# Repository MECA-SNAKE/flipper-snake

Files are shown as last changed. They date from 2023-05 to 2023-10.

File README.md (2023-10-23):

https://meca-snake.github.io/flipper-snake/

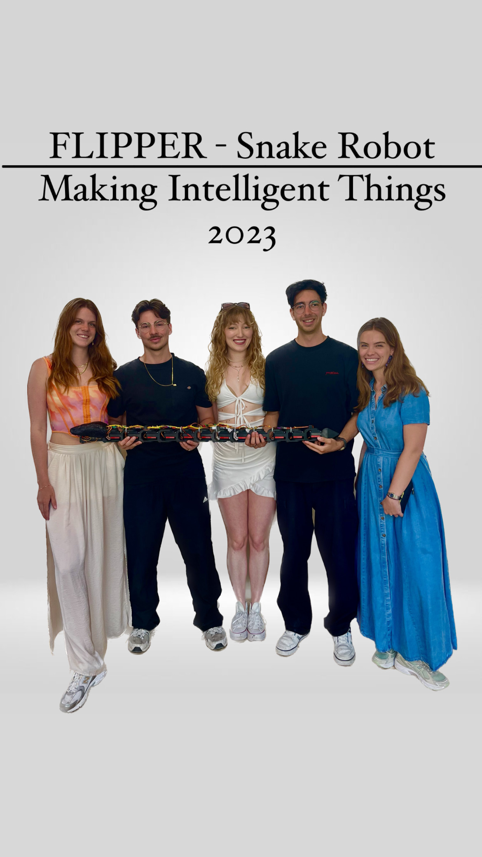
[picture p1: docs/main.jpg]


Meet Flipper, an impressive snake robot measuring 1m20 and crafted from 13 intricately designed 3D-printed pieces. With its remarkable capabilities, Flipper elegantly navigates and explores its surroundings. This versatile robot boasts 3 distinct modes of motion: Inchworm, Concertina, and Undulation. The Inchworm mode enables precise inch-by-inch movement, the Concertina mode mimics the graceful accordion-like motion. In the Undulation mode, Flipper effortlessly slithers with a mesmerizing sinusoidal movement. Flipper's innovative design and diverse locomotion options make it a remarkable robotic creation. 

## News
* May 2023: Present project outcome in a public forum
* June 2023: Invitation from the EPFL Computer Science and Communication Systems Section to present Flipper to the Section's teachers at the Lausanne Palace
* Octobre 2023: Invitation to the VIScon 2023 symposium at ETH in Zürich







## How to reproduce the snake

### Mount the snake
* Take the stl files of the snake. Print the main piece 8 times (the one without the holder for a battery), 3 times the one that can hold a battery, the tail one time, the head one time and the snake head on time. Pay attention to fully clean the holes for the wheels to avoid contact with the pieces
* Print also the 28 wheels and the 14 sticks to place them below the pieces
* Follow the first animation of the piece design section to mount the pieces together with the bearings and servos. Don’t forget to place the pieces that can hold a battery. You can place them where you want however keep in mind that they can help to pass cables through them. After that you should have a full length snake. 
* Mount the boards on the head piece as you will see in the animations, and the battery in its holder. A crucial stage now is to make the cable management. Follow the images and the details below in the readme to see how to connect all the cables, as well as connecting the cables to the PCA board, NodeMCU, the DC-to-DC converter and the battery. Exercise caution during this step, ensuring that you correctly connect the cables as per the provided diagram. Regarding the cable lengths required for a complete assembly, the yellow cable spans 5 meters, while the ground and the plus cables measure 3 meters each. For the head of the snake, you can place it as you want.

### Arduino code
* Download these following softwares on your computer : 
* the Arduino IDE app
* Set the Arduino IDE with NodeMCU ESP8266 (there are tutorials if needed on YouTube) 
* Add the board manager link in Arduino IDE Files < Preferences < Additional Board Manager URLs field : https://arduino.esp8266.com/stable/package_esp8266com_index.json 
* Install the esp8266 toolchain in the Tools -> Board -> Boards Manager
* Select Tools->Board->"ESP8266 Boards (some version)"->"NodeMCU V0.9 (ESP-12 Module)".
* And you may need to install : https://www.silabs.com/developers/usb-to-uart-bridge-vcp-drivers?tab=downloads

* Clone the Arduino code from the arduino-commands repository 
* Connect your computer to the ESP8266 board via a micro usb cable
* Change the ssid and password of your hotspot
* Upload the code to the board and connect the battery to the snake
* Verify in Serial Monitor that it prints Wifi Connected indicating that the board successfully connected to your wifi

### The React Native App
* Clone the react-native-esp-app repository locally on your machine. 
* Install NodeJS for your operating system
* Install expo-cli with this terminal command : `npm install -g expo-cli` / If there is a problem with windows restriction, copy paste this command into the Powershell `Set-ExecutionPolicy -Score CurrentUser -ExecutionPolicy RemoteSigned`
* Install expo client on your phone
* Navigate to the : react-native-esp-app folder on your computer. In App.tsx change line 53’s IP address with the IP address that will be printed in the Serial Monitor of the Arduino IDE app. 
* Write `expo start` in the terminal
* Scan the QR code with your phone, which will open the app

### How to launch the snake
* Enable your hotspot
* Start the app on your phone
* Connect the battery to the snake
* Have fun!

## Motivation 
Serpentine robots are a groundbreaking innovation in robotics, captivating researchers and engineers with their unique physical characteristics and versatile capabilities. These flexible and slithering machines excel at navigating complex and confined spaces, offering immense potential in various fields, including search and rescue operations, industrial inspections, exploration, medical applications, surveillance and security, and hazardous environments.

In search and rescue scenarios, robotic snakes play a crucial role. Unlike traditional robots, they excel at maneuvering through narrow and cluttered environments, such as collapsed buildings or debris. With their flexible bodies, they can easily navigate tight spaces, climb obstacles, and explore inaccessible areas. Equipped with cameras and sensors, these robots transmit real-time data, aiding rescuers in locating survivors and assessing surrounding conditions.

Our objective was to undertake a project that would have practical relevance in the real world. The field of robotics is continuously evolving, and we saw the development of a robotic snake as a chance to deepen our understanding of robotics and gain practical experience in designing and building complex systems. As a group of five computer scientists with backgrounds in communication systems and computer science, we possess a solid understanding of algorithms, programming languages, and system design, which are essential components in the development of a robotic system.

While we may not have had direct experience in building robotic systems, we embraced the opportunity to expand our expertise. We were committed to researching the specific technologies and methodologies required to develop a robotic snake, including mechanical engineering principles and electrical systems.

## Preparation for the project
After doing extensive research, we encountered 2 existing snake projects that served as profound inspiration for Flipper: 

* https://www.instructables.com/Bioinspired-Robotic-Snake/
* https://www.instructables.com/Snake-Robot-1/

Furthermore, our journey led us to a valuable encounter with a PhD student from the Bio-Robotic Lab at EPFL. During our conversation, she generously shared her insights and recommendations for a successful project within a shorter timeframe. One key suggestion was to focus on a signle degree of freedom for motion, ensuring efficiency and feasability. Additionally, she encouraged us to explore the mechanics behind sinusoidal functions, shedding light on the intriguing undulated motion exhibited by snakes. These valuable ideas and guidance have profoundly influenced our approach to Flipper's developpement. 

## Conception

### Material

* 1 LiPo Battery 2S 7.4V
* 1 ESP8266 microcontroller
* 1 PCA9685 servo motor controller
* 1 LM2596 DC-to-DC converter
* 12 DS6225MG Servo motors
* 48 M3 0.5 inserts
* 48 M3 10mm screws 
* 1 Adapter cable ModelCraft 58604
* A lot of cables and electric sheath
* 28 small lego wheels
* 2 Lasers 650mn 5V
* 12 bearings 12x8mm

### Piece design

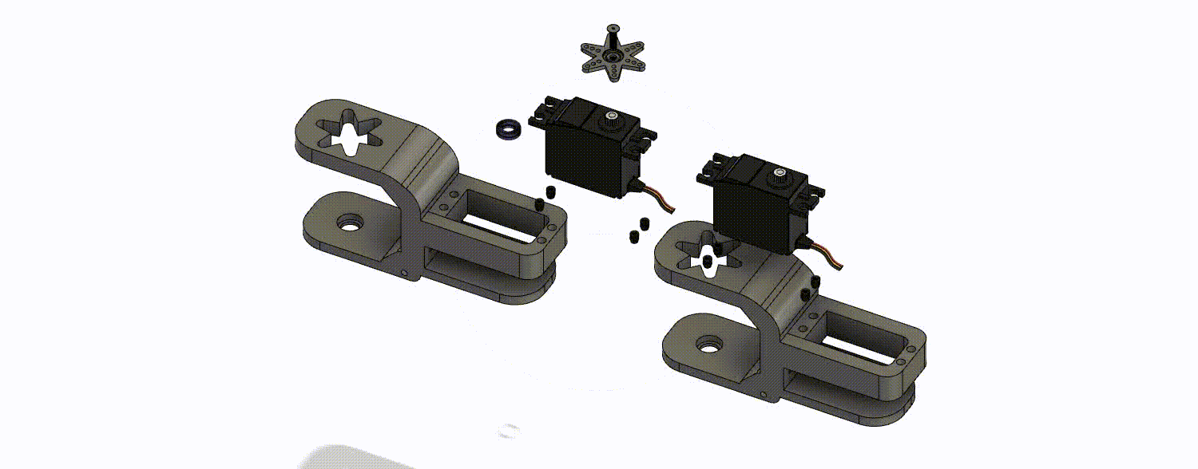
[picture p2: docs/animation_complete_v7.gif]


#### 1.Important features

Initially, our design concept for Flipper was relatively straightforward. However, as we delved deeper into the design and development process of the pieces, we faced a number of challenges. Our primary objective was to create a joint capable of achieving a broad range of motion, ideally spanning at least 180 degrees. Additionally, we strived to ensure that the servo was securely held in place, with minimal looseness or play. Overcoming these obstacles became essential in achieving the desired functionality and stability of Flipper's design.

To accomplish our goal, we developed an interlocking piece system featuring a single axis of rotation. This design enabled us to achieve a wide range of motion, spanning from approximately -30 to 230 degrees, with the middle position set at 90 degrees. By utilizing this system, we ensured that Flipper could move smoothly and effectively within this expansive range.
For the servo motor, we opted for a simple yet effective holder design. This holder featured four holes strategically positioned to allow us to securely fasten the servos in place. To further enhance stability and ensure a tight fit, we utilized inserts with the appropriate thread pitch.

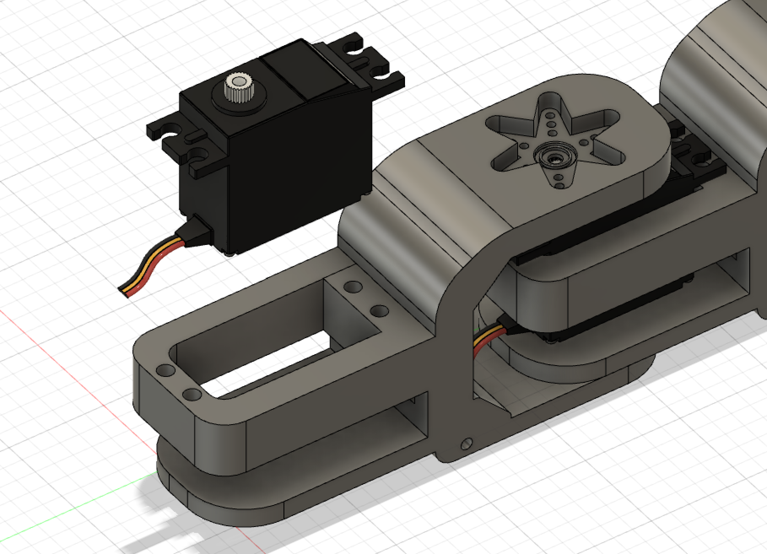
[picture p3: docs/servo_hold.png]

#### 2. Movement propagation

The subsequent obstacle we faced involved transmitting the motion from one piece to another along the servo's axis of rotation. To address this challenge, we leveraged the star-shaped mounting head of a servo as a reference point. By incorporating a corresponding hollow shape in our own piece design, we were able to seamlessly connect and interlock two segments (refer to the attached picture).

Our decision to utilize a star-shaped head stemmed from its advantageous feature of offering multiple points of contact with the subsequent piece. This choice greatly facilitated the transmission of movement, making it more manageable to drive the desired motion. 

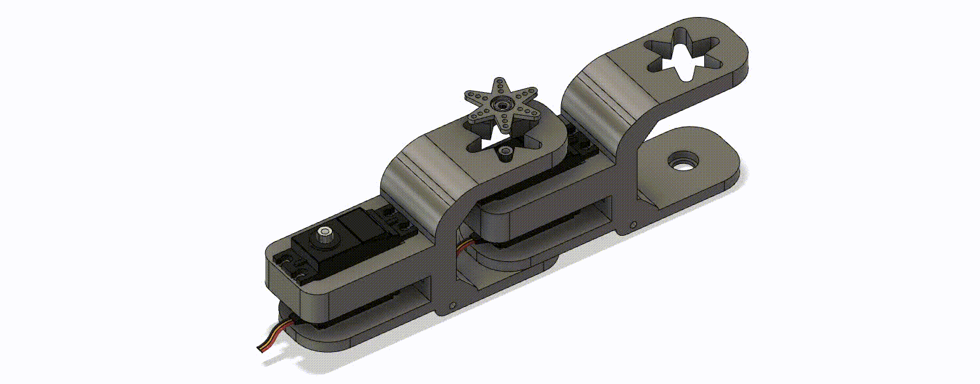
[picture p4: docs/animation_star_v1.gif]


To ensure a secure fit and prevent any dislocation, we implemented two additional features. Firstly, we created an extrusion beneath the surface of one piece, and corresponding to it, a hole in the second piece. This design allowed for a solid interlocking system between the two pieces.
Secondly, to minimize friction between the pieces, we incorporated a bearing. The extrusion was designed to fit snugly into the bearing, enabling smooth movement and reducing friction.
These modifications proved effective in achieving a well-fitting and stable assembly.

Although this approach proved highly successful, implementing the design was not without its challenges. The intricate shape posed complexities that necessitated multiple attempts and iterations. Through perseverance and a process of trial and error, we ultimately achieved a well-fitting shape that perfectly served our intended purpose.
 
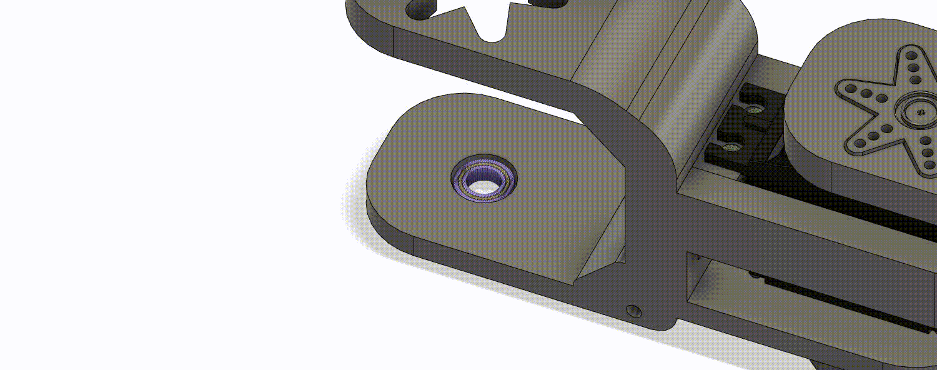
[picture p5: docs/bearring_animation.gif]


#### 3. Allowing movement

A fundamental and indispensable component that ensures the accurate movement of the snake is the incorporation of wheels. The lateral friction generated by these wheels imparts a unidirectional force, enabling the snake to move effectively. This mechanism aims to mimic the natural function of snake scales, which enhance friction in specific directions. Our primary objective was to minimize the visibility of the wheels, preventing any misperception that they are directly driving the snake's motion, contrary to its undulated movement. The meticulous effort invested in concealing the wheels yields a sleek and sophisticated design, emphasizing the clean aesthetics of the overall structure.

#### 4. Designing the Head

The design of the head was significantly influenced by our considerations for cable management and electronic components. Our goal was to accommodate a microcontroller, servo board, converter, and all the necessary circuit cables within the head. While the assembly of these components inside the head may appear somewhat intricate, we believe it to be a sound approach. This design choice offers the advantage of providing protection for all the internal elements, despite the potential complexity of the arrangement.

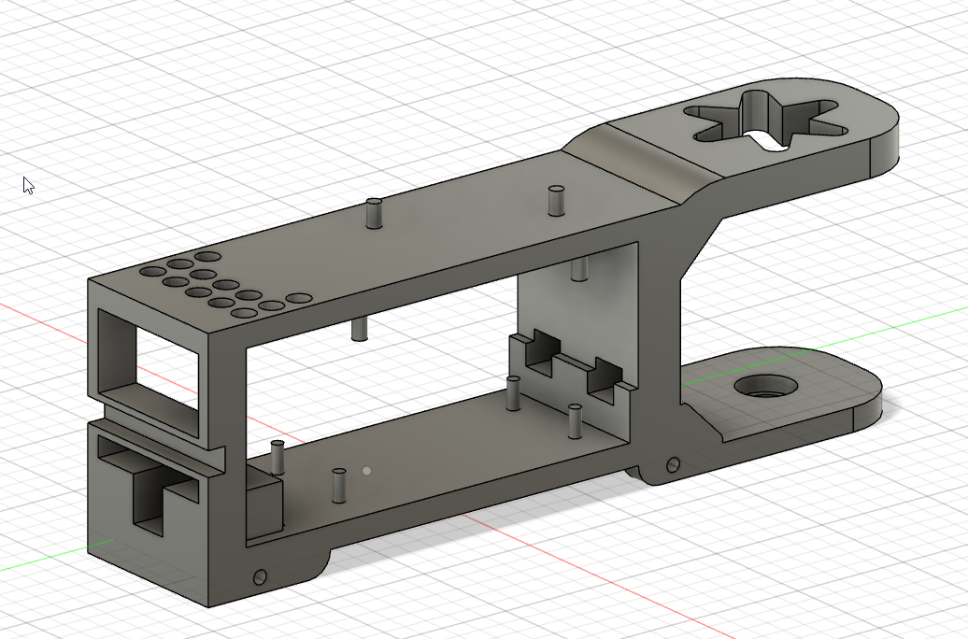
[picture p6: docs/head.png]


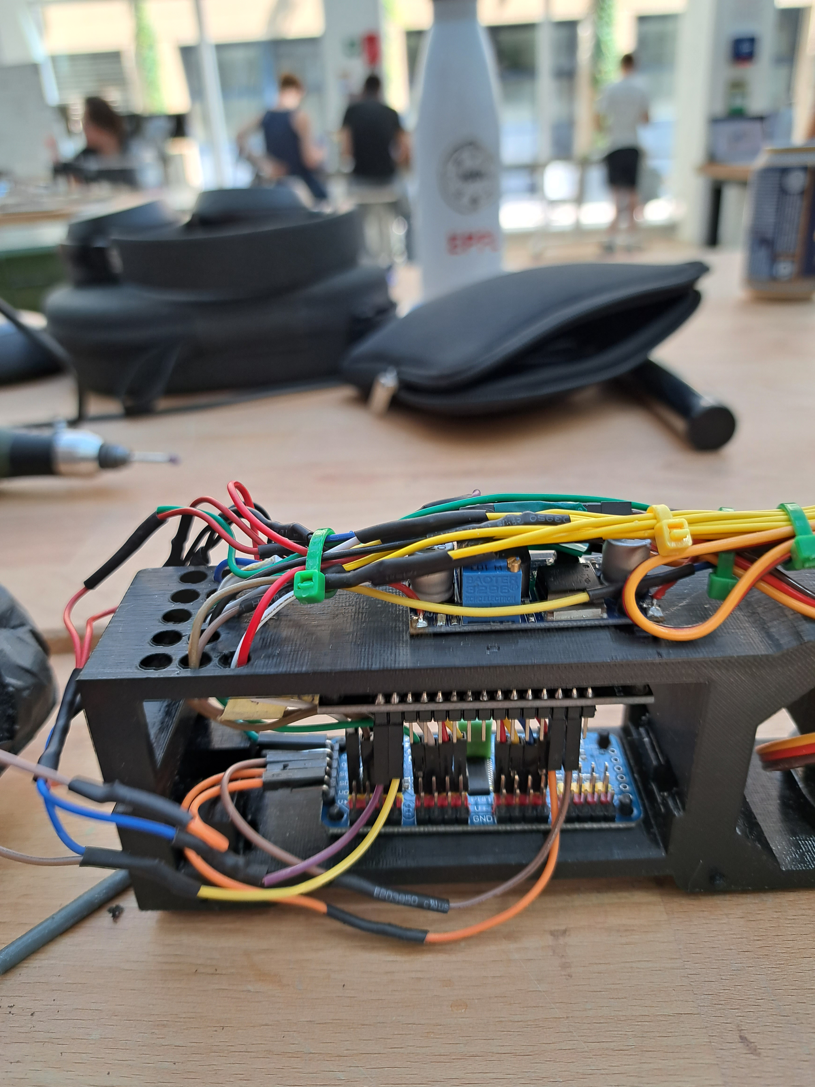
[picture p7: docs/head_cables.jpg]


#### 5. Thinking ahead

The design aspect of the project is of utmost importance, as even the smallest oversight could lead to the failure of the entire endeavor. We made a conscientious effort to anticipate and address all potential challenges that could arise. One such challenge was cable management. To ensure a polished end result, we incorporated holes in each piece to allow the cables to seamlessly traverse from the tail to the head. However, we encountered a setback as these holes turned out to be too small to accommodate the servo's cable end.

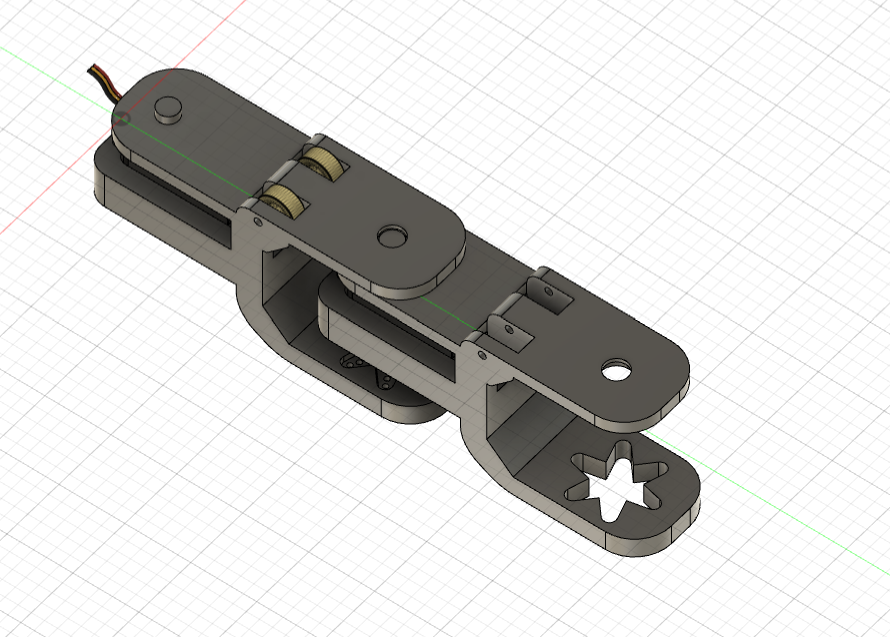
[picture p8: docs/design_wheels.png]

    
### Electronics

The primary role of our electronic components is to effectively control the servo motors. To accomplish this, we utilized a PCA9685 board specifically designed for transmitting PWM (Pulse-Width Modulation) signals to the servo motors. This board was then connected to our microcontroller, which housed the necessary code for servo movement. However, we encountered several challenges when it came to powering the entire circuit, which will be elaborated upon in the subsequent sections.

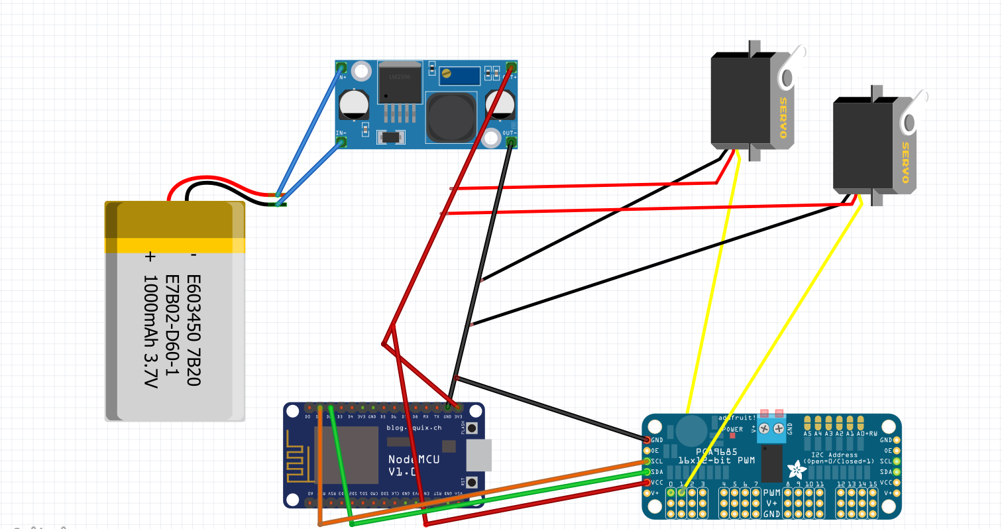
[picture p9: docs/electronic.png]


#### 1. Placing the Battery

Initially, our plan involved utilizing three 7.4V Lipo batteries, which necessitated careful consideration regarding their placement and accessibility. To securely accommodate these batteries, we devised three additional pieces with integrated holders. This design adaptation ensured that the batteries were not only firmly held within the snake but also easily replaceable when required.
However, following an extensive discussion with members of the DLL building and Professor Koch, we made the decision to reduce the battery count to just one. The consideration was primarily due to the challenges associated with parallel connection to achieve a higher current output, which could potentially risk damaging the batteries. Given that these batteries are specifically designed to deliver a significant amount of current within a short duration, opting for a single battery proved to be a prudent choice

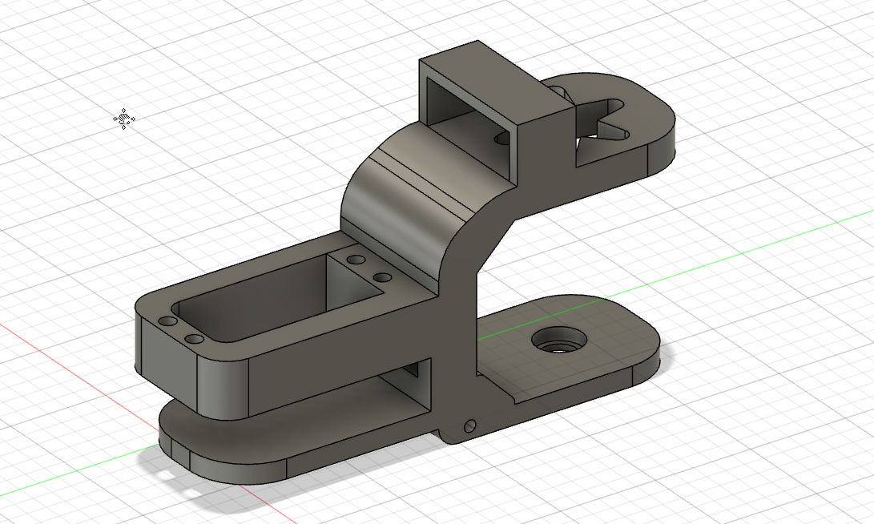
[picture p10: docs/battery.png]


#### 2. Powering the servos directly from the battery

Upon examining the electronic schema, an intriguing observation arises: the servo motors' positive and negative cables are not directly connected to the PCA9685. Instead, we have implemented a configuration where all the servo grounds are connected to the battery ground, and all the servo positive terminals are linked to the battery's positive terminal.
This unique arrangement serves a specific purpose within the circuit design, providing a common ground for the servos and maintaining a shared power source through the battery's positive terminal. In fact this idea was from our professor because we were worried that there would be too much current from the servos. Using only the signal pins means we don't have to power the servos via the PCA9685. 

#### 3. Voltage and Current

Our circuit design faces various constraints due to specific voltage and current requirements of different components:

* The servo motors operate within a voltage range of 4.8-6V.
* The ESP8366 module operates at 3.3V.
* The ESP8266 module requires a voltage supply of 5V.
* The battery supplies a voltage of 7.4V.
* The PCA9685 board's circuit needs a 5V voltage supply.

Since we utilize the PCA9685 board solely for servo control and not for powering them, we do not need to utilize the V+ port, which is intended for servo power supply. As a result, we power the board's circuit exclusively through the VCC port, requiring a 5V input voltage. Considering the battery supplies a voltage of 7.4V, we incorporated a DC-to-DC converter to transform the battery's output voltage to 5.5V. This voltage level proved sufficient to power the servos while remaining within an appropriate range for the microcontroller and the board's controller circuit 

#### 4. Placement of the electronic components

Minimizing the number and size of electronic components posed a significant challenge in our project, particularly due to the limited surface area available on the snake for their placement. After careful consideration, we devised a solution: consolidating and integrating all the electronic components inside and above the snake's head. This decision proved advantageous as it centralizes all the electronics in one location.
Although one might argue that this approach leads to a cluster of cables near the head, we deemed it a superior alternative to the idea of routing cables to both the tail and the head. By concentrating the cables in one area, we achieved a more streamlined and organized design. Moreover, having all the electronics in close proximity is convenient as it provides easy access to the necessary components.

### Cable Management

Efficient cable management is intricately intertwined with the electronic design of our project. To tackle this challenge, we successfully employed numerous zip ties to neatly bundle the cables together. At this juncture, we implemented a thoughtful design for the head, incorporating small holes that allow the cables to pass through and connect to the board and microcontroller. 

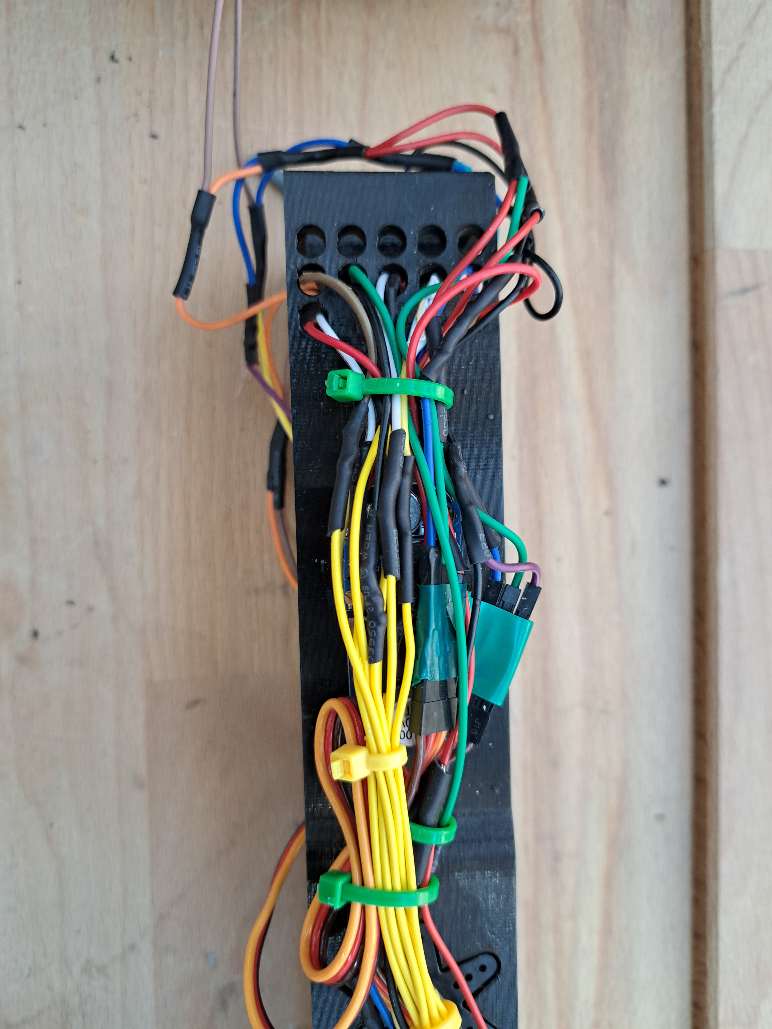
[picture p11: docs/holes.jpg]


One of the primary challenges pertaining to the cables revolved around soldering the positive and negative wires of all the servos to the corresponding terminals of the battery after the converter. While the process itself was repetitive and not excessively complex, it required utmost caution to avoid any missteps. A single missed solder joint would necessitate starting over from the beginning, amplifying the importance of being attentive to detail throughout the soldering process.
  
## Software Design

The software architecture is structured into three main components: **the motions**, the code for **the UI** and the code for **the client-server communication**. In this section, we will delve into the implementation details and the reasoning behind each component. While the UI code primarily focuses on the design aspects of the application and utilizes React principles, we will specifically highlight the functionality of the joystick, which plays a crucial role in fully controlling the snake.

### React Native App

The snake control application is a mobile app developed using React Native, a popular framework for building cross-platform applications. Written in TypeScript, a statically-typed superset of JavaScript, the code ensures code reliability through type checking. The snake control app allows users to control the snake's movements wirelessly. The application utilizes various components and libraries to create 2 main views: a home view where we can select the mode of motion and other parameters, and a user-friendly interface to control the snake after activating a motion.

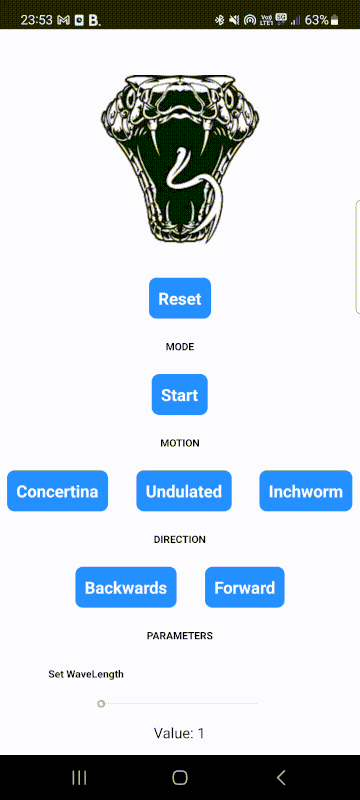
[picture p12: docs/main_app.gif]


The "game" mode of the application is designed in a way that facilitates the user experience of controlling the snake. We used a joystickbn to allow the user to control the snake. The app has taken various different faces throughout our project, initially, our goal was to be able to allow the user to enter any possible combination of parameters for the wavelength, amplitude, speed and frequency, but the more we tested out our snake's motion, we realized that random parameter inputs were not to the snake's advantage. We decided to abandon this idea to prevent the snake from making sudden movements and damaging itself. We have pre configured parameter inputs to plug into the snake at any moment the user wants it to turn right, left, go forwards or backwards. It's important to note that the application doesn't allow the user to go left or right if the inchworm motion is enabled and doesn't allow the user to go anywhere but forwards if the concertina motion is enabled. This is because we have to flip the snake over when the inchworm motion is enabled, imposing only 1 degree of freedom on the vertical axis.

Finally, with some solid background of computer science studies, we thought that React Native was a very straight-forward and intuitive framework to use for our snake project. By combining efficient state management, network communication, and intuitive user interface design, the application offers a seamless and engaging experience for controlling the snake wirelessly.

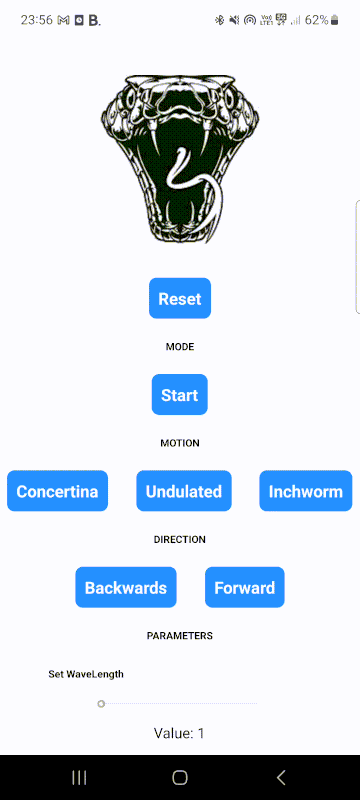
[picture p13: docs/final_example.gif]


### Client-Server communication

To establish communication between the ESP8266 and the React Native app, we initially planned to utilize Bluetooth Low Energy (BLE) due to its simplicity and ease of deployment. However, we soon realized that the ESP8266 lacked a Bluetooth module and instead possessed a Wi-Fi module. This prompted us to change our approach and leverage the Wi-Fi capabilities of the ESP8266.
To enable communication between the React Native app and the ESP8266, we deployed a web server on the ESP8266. This web server served as a central hub to handle incoming POST requests from the app, allowing for seamless control of the snake. Within the web server, we implemented multiple routes to handle various POST requests from the client (the app). One example is the route designed for resetting the snake. When the user pressed the "reset" button in the app, a corresponding POST request was sent to the designated endpoint on the ESP8266. This triggered the necessary actions to reset the snake to its initial state. Here is the code that illustrates the "receive" function on the server side.

``` cpp
// Server-side code
server.on("/reset", HTTP_POST, [](AsyncWebServerRequest *request) {
    if(request->hasParam("value", true)) {
      AsyncWebParameter* p = request->getParam("value", true);
      int value = p->value().toInt();

      if(value == 0) {
        motion_snake = NONE;
      }
      request->send(200, "text/html", "good"); 
    } else {
      request->send(404, "text/html", "Error reset"); 
    }
  });

```

```ts
// Client-side code
const App: React.FC<Props> = () => {
    // ... 
        
    const handleButtonReset = () => {
        sendRequests("value", "0", "reset");
    }
    
    // ... 

    function sendRequests(key: string, val: string, root: string) {
        axios.post('http://192.168.236.121/' + root, {
          [key]: val
        }, {
          headers: {
            'Content-Type': 'application/x-www-form-urlencoded'
          }
        }).then((response) => {
          console.log(response);
        }, (error) => {
          console.log(error);
        });

        }
   }  
   
   // ... 
   
   return (
        // ...  
    
        <TouchableOpacity onPress={handleButtonReset}>
          <Text>Reset</Text>
        </TouchableOpacity>   
        
         // ...        
   )
}
```

On the client-side (the app), the application harnesses the power of the axios library to facilitate HTTP requests, allowing seamless communication between the app and the snake robot. Axios serves as a valuable tool for sending commands and receiving data from the snake.
Within the application, a function called "sendRequests" takes charge of sending control commands to the snake. This function enables various actions, such as initiating or halting the snake's motion, adjusting parameters such as wavelength and amplitude, and selecting different motion modes like concertina or undulated. By utilizing axios, these commands are efficiently transmitted to the snake, allowing for precise control and customization of its behavior.

### Movements and Controls

Let's dive into the motion capabilities of the snake and how we control the servos from the microcontroller. As previously mentioned, the servos are controlled by a specialized board using pulse-width modulation (PWM) signals. This method allows us to precisely control the average power delivered to the servos.
In simple terms, we can send pulses of a specific length to the servos, which will move them from one angle (Angle A) to another angle (Angle B). By manipulating the length of these pulses, we can control the position and movement of the servos.
Now, let's discuss the mathematical functions that govern the snake's motion and how they interact with the phone app, particularly the joystick control.

``` cpp
#define MIN_PULSE_WIDTH 800
#define MAX_PULSE_WIDTH 2000
#define FREQUENCY_SERVO 50

Driver driver = Driver(0x40);

int rotate_with_min_max(int servo, double angle) {

  int pulse_wide = map(angle, 0, 180, MIN_PULSE_WIDTH, MAX_PULSE_WIDTH);

  return int(float(pulse_wide) / 1000000 * FREQUENCY_SERVO * 4096);
}

driver.setPWM(5, 0, rotate_with_min_max(5, 80));
```

In the provided code snippet, you can see that we define the minimum and maximum pulse widths as 800 and 2000 microseconds, respectively. These values represent the range of pulses that we can send to rotate the servos, allowing us to move them from 0 to 180 degrees. For instance, a pulse width of 800 microseconds would correspond to a servo position of 0 degrees.
Additionally, we set the frequency to 50Hz, which means that we can update the position of each servo 50 times per second. This frequency ensures smooth and responsive servo movements.
To rotate a specific servo to a desired angle, we use the "setPWM" function. In the provided example, the function "rotate_with_min_max" is called to convert the desired angle (80 degrees in this case) into the corresponding pulse width value within the defined range. This conversion is achieved using the "map" function from the Arduino library, which maps a range of values to another range of values.
Finally, it's important to note that the PCA9685 board operates at a 12-bit resolution. Therefore, the pulse width value needs to be converted into a 12-bit value (ranging from 0 to 4095) to match the resolution of the PCA9685.

With the understanding of how the servos are controlled, let's now explore the different motions implemented for the snake.
  
#### 1. Inchworm



To achieve an inchworm-like motion, a modification is required in the snake's position. Instead of moving in a lateral undulating manner, we need to flip over the snake to allow it to move freely in the vertical direction and straight forward, rather than to the side.
By flipping the snake, the direction of movement changes, and the snake can simulate the inchworm motion. This modification involves adjusting the sequence of segment movements and the coordination between the head and tail segments.
To move, the robotic inchworm extends one segment forward while simultaneously contracting the adjacent segment backward. This action creates a looping or undulating motion similar to that of a real inchworm.

#### 2. Concertina



In the video, you can observe that the snake performs a unique motion characterized by contracting itself with a specific wavelength, lengthening half of its body, contracting the front half once again, and simultaneously lengthening the tail. Surprisingly, this motion was proved to be the most challenging aspect of a snake's movements, mainly due to its "step-by-step" nature on the ground.
Extensive research revealed that this particular motion, known as the concertina movement, is inherently complex, even in other snake projects. It presents greater difficulties compared to the undulated movement, which involves a smoother wave-like motion.
The development and successful implementation of the concertina motion required careful analysis, experimentation, and fine-tuning to achieve the desired results. The challenges encountered during this process highlight the intricate nature of replicating snake locomotion in a robotic systems.

#### 3. Undulated

Lateral undulation, the typical undulating movement of a snake, was the primary locomotion type we aimed to achieve in our project. Implementing this motion required a closer look at the underlying mathematics.
Surprisingly, the equation for a simple undulation was not overly complex; it could be represented by a sine wave. In fact, let's consider it over his period 2$\pi$ with 12 equidistant points that represent the 12 servo motors of our snake.

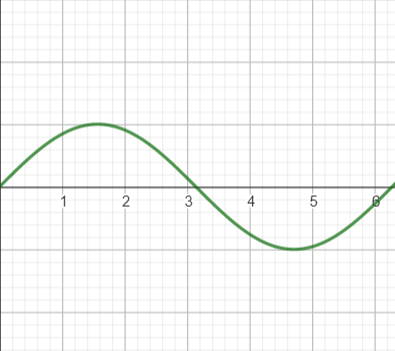
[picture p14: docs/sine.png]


We can see that undulation is very similar to this graphed function, and to trigonometric functions in general. Let's now add some phase term to see how it changes the graph

--> image phase pi/4 avec 12 points

This function can be written like this $\sin(x + \frac{\pi}{4})$, where $\frac{\pi}{4}$ is the phase term, meaning that we shift the function to the left with a value of $\frac{\pi}{4}$. The idea to simulate a wave form is to now continuously change the phase term from 0 to 2$\pi$.

<iframe src="https://www.geogebra.org/calculator/bxwqg3t7?embed" width="800" height="600" allowfullscreen style="border: 1px solid #e4e4e4;border-radius: 4px;" frameborder="0"></iframe>

We can observe a wave that appears to propagate. In this scenario, each servo corresponds to a point on the graph's period, and each point represents a value of the sine function at a specific input x. When animated, the time variable t can now be interpreted through a continuously changing phase term.
If we assume that each servo's value needs to align with one of these points, then its value will resemble the sine wave at a particular x coordinate. 

In theory, this may seem logical, but there is a curcial consideration to keep in mind. While our concept of undulation exists in a continuous world, our robotic snake consists of discrete components with **fixed length**, unlike a real snake that can extend its body. This aspect posed a significant challenge and was a source of concern for us. No matter how well-designed our parts were, implementing a continuous sine wave equation on our snake remained uncertain.
However, through rigorous testing and experimentation, we discovered that our implementation of the sine wave equation for lateral undulation did indeed work. The coordinated movement of the servo motors and the discrete segments produced a convincing simulation of the undulating motion observed in real snakes. The final function for this motion is the following

``` cpp
void undulated_motion() {
  for(int i = 0; i < 360; i++) {
  
    float brads = i * 3.1415 / 180.0; 

    for(int j = 0; j < N_SERVOS; j++){  
      
      if(dir_snake == FORWARD) {
          rotate(j, 90 + offset + amplitude * sin(frequency * brads + (wavelength * j * 2 * 3.1415) / (N_SERVOS - 1)));
       } else {
          rotate(j, 90 + offset + amplitude * sin(-frequency * brads + (wavelength * j * 2 * 3.1415) / (N_SERVOS - 1))); 
      } 
    }
   delay(10);
  }
}
```
First we have an outer loop going from 0 to 2$\pi$ that representing the input values of the function (it's domain of definition). We convert them into radians to make easier the calculation. Then we have this inner loop that represent the servos taking values from the sine wave over time. The function is different because we added parameters to change the behaviour of the function. What we see is that at a specific value `i` (so fixing the wave at a certain time), each servo is taking some value between `[90 - amplitude, 90 + amplitude]` accordingly to the shape of the sine function for a specific wavelength. Additionnally, to say is that to change the speed of the wave, we can add a speed term, here called `frequency`, such that we complete a full period of the function in a different amount of time. Interpeting this with the complexe plane, this represent the speed at which we rotate around the unit circle. A last thing to say is that to make the snake go to the right or to the left, we add an integer value called `offset`, to the base angle which is 90 degree. With that, each servo will go a little bit more to the left or to the righteach each point in time.

We have now the time to explain how the joystick works to control the snake. We decided at the beginning of the project that we will only control the undulated motion because it was already quite challenging for one motion. Since controlling a snake is really close to a small electric car, a joystick is a great idea to move it. To make a joystick in react native, we needed a Gesture Handler framework called `react-native-gesture-handler` to handle the events of our fingers on the screen. After that, we created a react component that looks like a joystick and that can print the angle between the vertical axis and the finger. Vertically it’s 90 degrees and we can go to the right until 180 degrees and to the left until 0 degrees.



Now the angle that we have can’t just be sent to the microcontroller. It’s because of our implementation of the sinusoidal function. Like we said, to make the snake go to the right, we add some integer to the base angle of the servo motors: 90 degrees. Since now we receive an angle between 0 and 180 degrees, we need to map the angle of the joystick to an offset range for the arduino code. 

``` cpp
AsyncWebParameter* p = request->getParam("off", true);
double value = p->value().toInt();

int off = 0;
if(value <= 180) {
   off = map(value, 0, 180, -11, 11);
   if(off != offset) {
        update_offset(off);
   }
   request->send(200, "text/html", String(off)); 
} else {
   request->send(200, "text/html", "nothing"); 
}
``` 
In this code snippet, we utilize a mapping technique to convert the received value angle from the app into an offset range of -11 to 11. To enhance the interaction experience, we have implemented two key improvements.
Firstly, considering that the joystick angle values are updated rapidly, and each angle is sent to the microcontroller, we optimize the code in the Arduino by modifying the offset only when it differs from the current value stored in the offset variable. This way, unnecessary updates are avoided, resulting in more efficient processing.
Secondly, we have incorporated a function to transmit only angles that are multiples of 10. By doing so, we ensure that the transmitted angles have a finer resolution and are more aligned with meaningful increments, facilitating smoother and more precise control.

```ts
function findNearestMultipleOf10(input: number): number {
    const remainder = input % 10;

    if (remainder <= 5) {
      return input - remainder;
    }

    return input + (10 - remainder);
  }
```

With this done, we have a relatively smooth way to change the direction of the snake. 

## Limitation

Our project has encountered several noteworthy limitations that have influenced our progress and achievements. It is essential to acknowledge and comprehend these limitations, as they have played a crucial role in shaping our decision-making process. Moreover, we have successfully developed solutions within these boundaries posed by these limitations. By recognizing and addressing these limitations, we gain valuable insights for future improvements and refinements, and can maximize our project’s potential.

### Sensors

Having managed to attain our project’s priority, a functional undulating snake, our desire was to implement additional features, such as sensors. 

At first, we implemented sensors that would be able to detect potholes in its path. By wanting to challenge and implement a more impressive sensor functionality, we hoped, in a second step, that the snake would detect not potholes but objects, walls or other obstacles in its path, and that it would avoid these obstacles, either by changing his course or by stopping. 

The HC-SR04 ultrasonic sensors, utilizes ultrasonic waves to measure distances and detect objects in its surrounding environment. The working principle of the HC-SR04 sensor involves emitting ultrasonic pulses and calculating the time it takes for the echoes to return. It consists of two main components: a transmitter and a receiver. The transmitter emits high-frequency sound waves, which propagate through the air and bounce off any objects in their path. The receiver then detects the echoes and measures the time interval between transmission and reception. By using the speed of sound as a constant, the sensor can calculate the distance to the objects based on the time taken for the echoes to return. 

```cpp
#define TRIGGER_PIN 12
#define ECHO_PIN 14
#define SOUND_VELOCITY 0.034
#define CM_TO_INCH 0.39370100

float distance_sensor() {
  digitalWrite(TRIGGER_PIN, LOW);
  delayMicroseconds(2);

  digitalWrite(TRIGGER_PIN, HIGH);
  delayMicroseconds(10);
  digitalWrite(TRIGGER_PIN, LOW);
  
  // Calculate the distance
  return pulseIn(ECHO_PIN, HIGH) * SOUND_VELOCITY/2;
}
```

The successful implementation of the Arduino code and the subsequent testing initially led us to believe that the sensor task was successfully completed. However, upon attempting to test the entire system, including the snake and sensors, we immediately observed that the snake was no longer performing its intended movements as programmed.

After conducting thorough research, we have determined that the Arduino ESP8266 lacks support for multi-threading, which accounts for the unexpected behavior of the snake. Specifically, the issue arises during the time that elapses from  the emission of high-frequency waves by the transmitter to the detection of echoes by the receiver. As a result, the snake becomes unable to execute its movement instructions concurrently.

To address this challenge, a viable solution would have been to utilize two interconnected Arduino ESP8266 devices - one dedicated to handling the snake’s movements and the other focused on sensor operations. This arrangement would have allowed for seamless collaboration between the two components, enabling them to function harmoniously and resolve the issue at hand.

### Concertina movement

Another goal we had originally envisioned to incorporate was to implement the concertina movement into our robotic snake's locomotion to navigate through narrow passages. This is a method of locomotion used by certain snake species in confined spaces. It involves the snake alternately anchoring parts of its body against the walls or objects and then pulling the rest of its body forward, creating accordion-like folds.
However, we faced challenges in implementing this complex motion due to the precise servo control and the internal force required. Anchoring the front portion of the body and extending it forward to pull the rest of the body along proved difficult. The inadequate grip of the wheels and the snake's insufficient weight made it challenging to generate the necessary downforce for effective propulsion. Due to insufficient downforce, the snake was pushed backward while extending it's front section, counteracting its forward movement. Similarly, when contracting the rear, the front part of the snake was pulled backward, causing it to remain stationary or make minimal progress.

### Second degree of freedom

Initially, our plan was to incorporate a secondary degree of movement that would allow the snake to slide over obstacles or steps. 
However, implementing this proved challenging since it required two servos per body part to enable both side-to-side and up-and-down motion. With our current setup of 12 servos, one for each body part, implementing this additional movement would have significantly increased the size of each piece, resulting in a larger and significantly heavier snake. Furthermore, our existing battery solution would not have been capable of powering an additional 12 servos. 
With additional time, we would have explored the possibility of introducing a secondary degree of movement to specific sections of the snake. For instance, we could have enabled the tail to mimic the rattling motion seen in rattlesnakes, or elevated the head to enhace sensory capabilities for better environmental scanning.

## Improvements

### Calibration of each servo

We could improve the robot by enhancing the calibration of the servos. Currently, we have observed a slight deviation to the right in the snake's movement. Upon investigation, we determined that the issue stems from the servos' range being from -20 to 160 degrees rather than the desired 0 to 180 degrees. This discrepancy is a result of servo calibration. To rectify this, we need to determine the precise pulse signal values that allow for movement to any angle between 0 and 180 degrees. Additionally, this calibration process must be done individually for each servo, rather than having a general minimum and maximum pulse width. With a more meticulous servo calibration, we can significantly enhance the snake's movement.

### Adding a new degree of freedom

Another important improvement involves introducing an additional degree of freedom, enabling the snake to lift its body upward. This added capability would facilitate a movement commonly observed in snakes known as "sidewinding," where the snake lifts a portion of its body to reduce friction and slither sideways. Incorporating this feature would greatly expand the range of movements the robot can perform.

Furthermore, it would be beneficial to incorporate sensors that prevent the snake from colliding with obstacles. Achieving this requires adding another NodeMCU and establishing communication between the two units. More details regarding this aspect will be discussed in the limitations.

### Replacing the wheels

Lastly, a noteworthy advancement would be to replace the wheels with a material that mimics the scales found on snakes. This modification would provide a more lifelike appearance to the robot, aligning it with the characteristics of actual snakes. However, it is important to note that this particular enhancement falls under the realm of a research-level project.

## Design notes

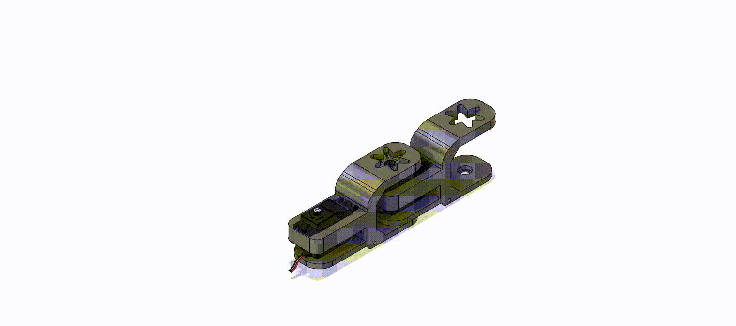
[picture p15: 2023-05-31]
docs/save_prototype_v4_animation_v3 v2.gif

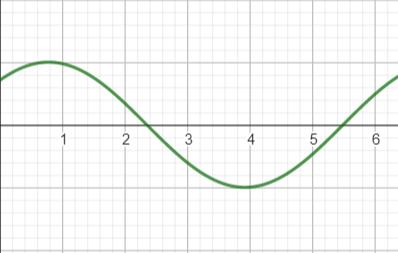
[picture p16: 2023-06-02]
docs/sine_phase.png

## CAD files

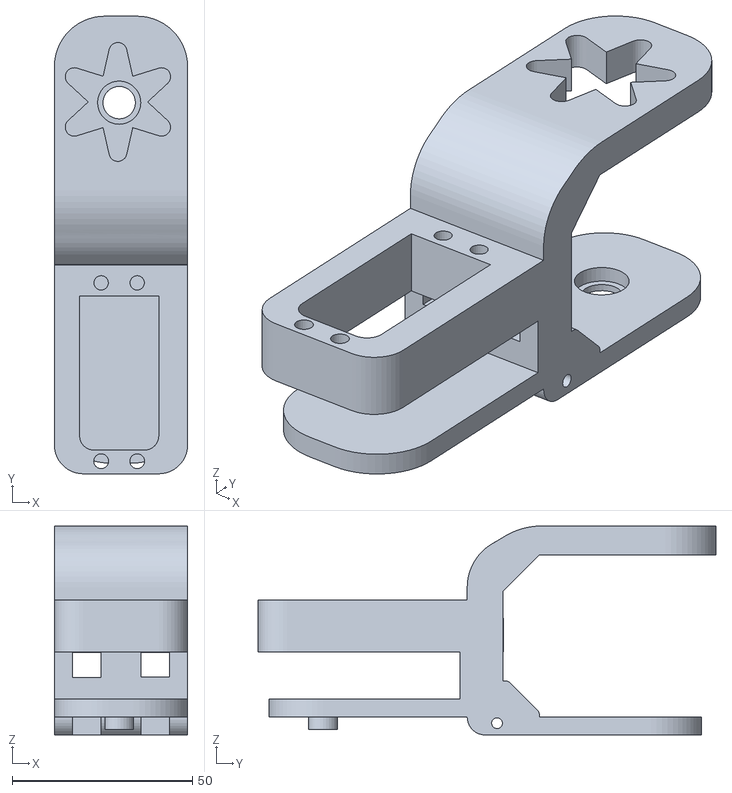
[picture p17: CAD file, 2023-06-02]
snake-print/main_piece.stl
37.0 x 127.0 x 58.0

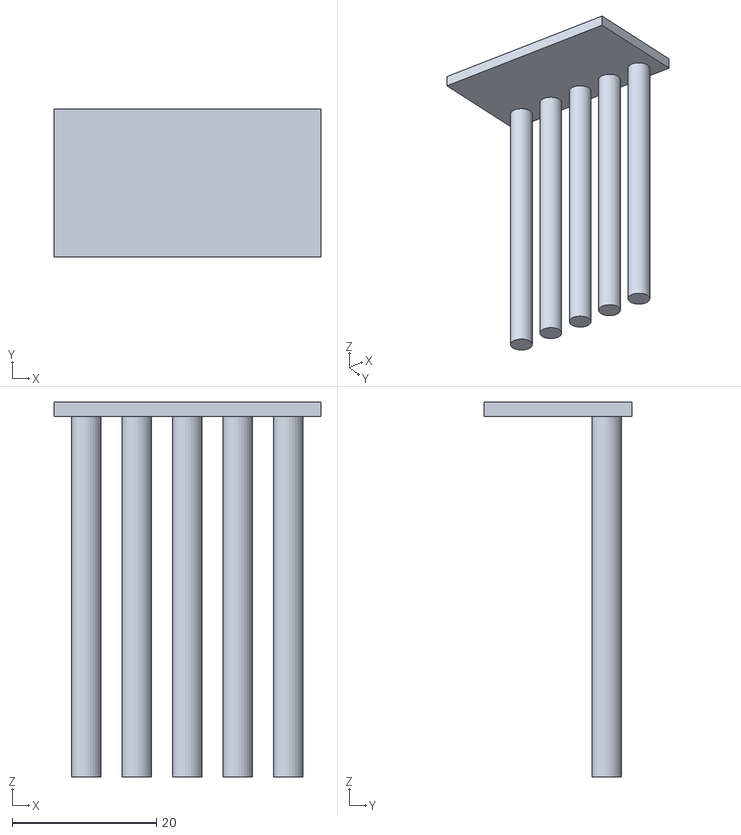
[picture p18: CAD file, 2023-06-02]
snake-print/head_fixation.stl
37.0 x 20.5 x 52.0

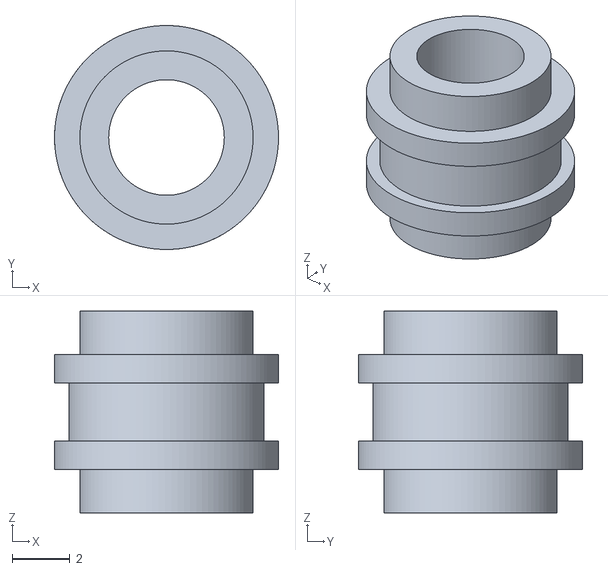
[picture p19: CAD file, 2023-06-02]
snake-print/wheels.stl
7.77 x 7.77 x 7.00

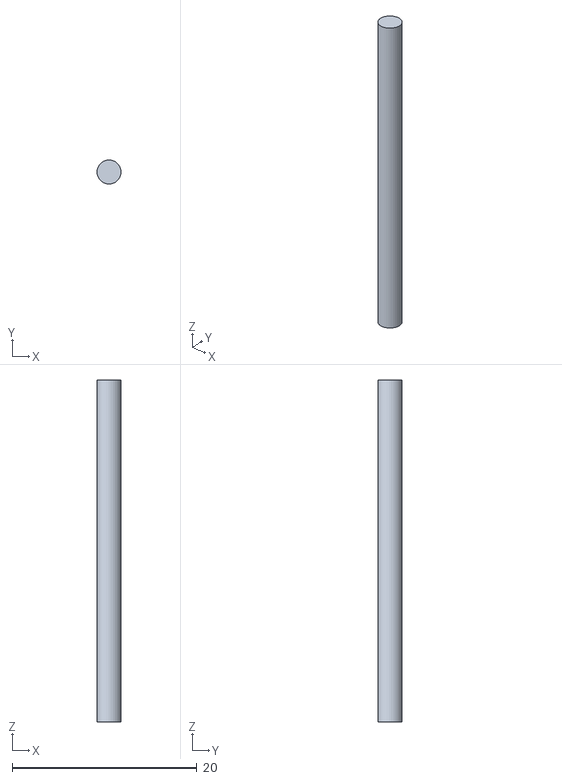
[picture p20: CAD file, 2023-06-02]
snake-print/wheel_axis.stl
2.59 x 2.60 x 37.0

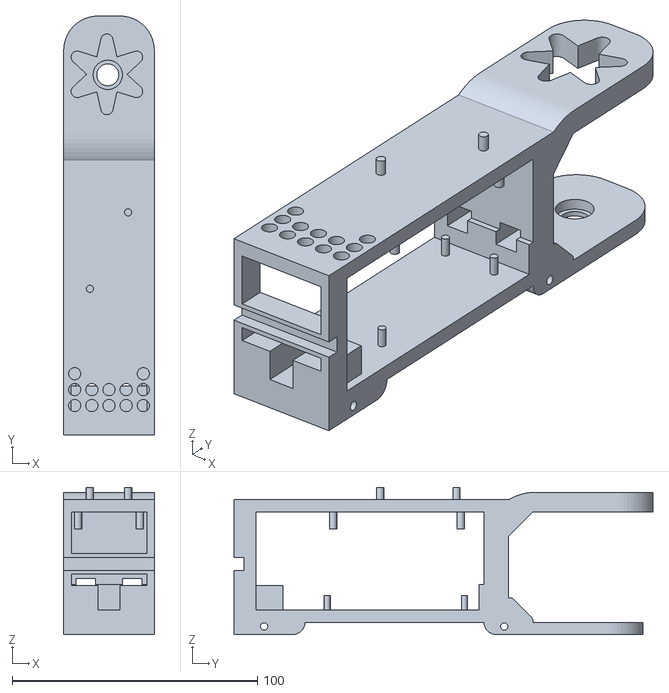
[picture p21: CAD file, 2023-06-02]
snake-print/head_piece.stl
37.0 x 171.0 x 60.0

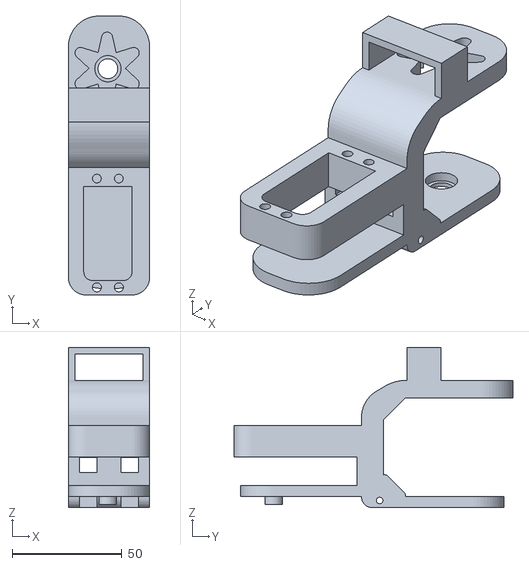
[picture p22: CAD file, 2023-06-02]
snake-print/piece_battery.stl
37.0 x 127.0 x 73.0

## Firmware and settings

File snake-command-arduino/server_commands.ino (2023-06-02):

// This file defines the code to command the snake

// -------------------------------------------------------------------------------------
// INCLUDES
// -------------------------------------------------------------------------------------
#include <Wire.h>
#include <Adafruit_PWMServoDriver.h>

#include <ESP8266WiFi.h>
#include <ESPAsyncTCP.h>
#include <ESPAsyncWebServer.h>

// -------------------------------------------------------------------------------------
// DEFINES
// -------------------------------------------------------------------------------------
#define MIN_PULSE_WIDTH 800 // best 895
#define MAX_PULSE_WIDTH 2000 // best 2095
#define FREQUENCY_SERVO 50

#define N_SERVOS 12
#define HEX_CHANNEL 0x40

#define DEFAULT_AMP 40.0
#define DEFAULT_FREQ 1.0
#define DEFAULT_OFF 0.0
#define DEFAULT_WL 1.0
#define DEFAULT_SPEED_INCH 1

#define TRIGGER_PIN 12
#define ECHO_PIN 14
#define SOUND_VELOCITY 0.034
#define CM_TO_INCH 0.39370100

// -------------------------------------------------------------------------------------
// TYPEDEF
// -------------------------------------------------------------------------------------
typedef Adafruit_PWMServoDriver Driver;

typedef enum {
  UNDULATED, CONCERTINA, INCHWORM, NONE
} motion;

typedef enum {
  FORWARD, BACKWARD, NO_MOVE
} direction;

// -------------------------------------------------------------------------------------
// PARAMETERS
// -------------------------------------------------------------------------------------
Driver driver = Driver(HEX_CHANNEL);

const char* ssid = "giogio_larue";
const char* password = "21ff99a2c0cd";

AsyncWebServer server(80);

int is_running = 0; // 0 -> not running, 1 -> running
motion motion_snake = NONE;
direction dir_snake = NO_MOVE;

double speed_inchworm = DEFAULT_SPEED_INCH;
double amplitude = DEFAULT_AMP;
double offset = DEFAULT_OFF;
double wavelength = DEFAULT_WL;
double frequency = DEFAULT_FREQ; 

// -------------------------------------------------------------------------------------
// MAIN FUNCTIONS
// -------------------------------------------------------------------------------------

// -------------------------------------------------------------------------------------
// -------------------------------------------------------------------------------------

// This function rotates a specific servo of an certain angle
int rotate_with_min_max(int servo, double angle) {

  int pulse_wide = 0;
  if(servo == N_SERVOS - 1) {
    pulse_wide = map(angle, 0, 180, MIN_PULSE_WIDTH, MAX_PULSE_WIDTH + 100);
  } else {
    pulse_wide = map(angle, 0, 180, MIN_PULSE_WIDTH, MAX_PULSE_WIDTH);
  }

  int al = int(float(pulse_wide) / 1000000 * FREQUENCY_SERVO * 4096);
  return al;
}

// -------------------------------------------------------------------------------------
// -------------------------------------------------------------------------------------

// This function rotates a specific servo of an certain angle (simpler)
void rotate(int servo, double angle) {
  int value = driver.setPWM(servo, 0, rotate_with_min_max(servo, angle));
}
/*
// This function return the distance of the first object in the direction of the sensor
float distance_sensor() {

  digitalWrite(TRIGGER_PIN, LOW);
  delayMicroseconds(2);

  digitalWrite(TRIGGER_PIN, HIGH);
  delayMicroseconds(10);
  digitalWrite(TRIGGER_PIN, LOW);
  
  // Calculate the distance
  return pulseIn(ECHO_PIN, HIGH) * SOUND_VELOCITY/2;
}
*/
// -------------------------------------------------------------------------------------
// -------------------------------------------------------------------------------------

// This function activates the inchworm's motion
void inchworm_motion() {

  for(int phi = 0; phi <90; ++phi){
    if(motion_snake == INCHWORM) {
      while(is_running == 0) {
        if(motion_snake != INCHWORM) {
          reset();
          delay(10);
          return;
        }
      }
      rotate(0, 90-phi);
      rotate(1, 90-phi);
      rotate(2, 90+phi);

      delay(10);
    } else {
      reset();
      delay(10);
      return;
    } 
  }

  for(int i = 0; i <= N_SERVOS-4; ++i){
    for(int phi = 0; phi < 90; ++phi){
      
      if(motion_snake == INCHWORM) {
        
        while(is_running == 0) {
          if(motion_snake != INCHWORM) {
            reset();
            delay(10);
            return;
          }  
        }

        if(i>0){
          rotate(i-1, 180-phi);
        }

        rotate(i, 2*phi);
        rotate(i+2, 180-2*phi);
        rotate(i+3, 90+phi);
        delay(10);

      } else {
        reset();
        delay(10);
        return;
      }
    }  
    delay(1000 / speed_inchworm);
  } 
}

int even = 1;

void concertina_motion() {

  if(even == 1) {
    for(int phi = 0; phi <= 90; phi++) {
     
      rotate(11, 90 - phi);
      rotate(10, 90 + phi);
      rotate(9, 90 + phi);
      rotate(7, 90 - phi);
      rotate(6, 90 - phi);
      rotate(5, 90 + phi);
      delay(5);
    } 

    delay(100);


    for(int phi = 0; phi <= 90; phi++) {
      rotate(5, 180 - phi);
      rotate(4, 90 + phi);
      rotate(3, 90 + phi);
      rotate(1, 90 - phi);
      rotate(0, 90 - phi);
      delay(30);
    }

    delay(100);

    for(int phi = 0; phi <= 90; phi++) {
      rotate(5, 90 - phi);
      rotate(6, phi);
      rotate(7, phi);
      rotate(9, 180 - phi);
      rotate(10, 180 - phi);
      rotate(11, phi);
      delay(5);
    }  

    delay(100);


    for(int phi = 0; phi <= 90; phi++) { 
      rotate(0, 180 - phi);
      rotate(1, 180 - phi);
      rotate(3, phi);
      rotate(4, phi);
      rotate(5, phi + 10);
      delay(5);
    }

    delay(100);

  } else {
    for(int phi = 0; phi <= 90; phi++) {

      rotate(11, 90 + phi);
      rotate(10, 90 - phi);
      rotate(9, 90 - phi);
      rotate(7, 90 + phi);
      rotate(6, 90 + phi);
      rotate(5, 90 - phi);
      delay(5);
    }  

    delay(100);

    for(int phi = 0; phi <= 90; phi++) {      
      rotate(5, phi);
      rotate(4, 90 - phi);
      rotate(3, 90 - phi);
      rotate(1, 90 + phi);
      rotate(0, 90 + phi);
      delay(30);
    }  


    delay(100);

    for(int phi = 0; phi <= 90; phi++) {
      rotate(5, 90 + phi);
      rotate(6, 180 - phi);
      rotate(7, 180 - phi);
      rotate(9, phi);
      rotate(10, phi);
      rotate(11, 180 - phi);
      delay(5);
    
    }

    delay(100);

    for(int phi = 0; phi <= 90; phi++) {
      rotate(0, phi);
      rotate(1, phi);
      rotate(3, 180 - phi);
      rotate(4, 180 - phi);
      rotate(5, 180 - phi);
      delay(5);
    }

    delay(100);
  }
}

// -------------------------------------------------------------------------------------
// -------------------------------------------------------------------------------------

// This function sets the snake in a straight line
void straight() {
  for(int i = 0; i < N_SERVOS; i++) {
    delay(500);
    rotate(i, 90);
  }
}

// -------------------------------------------------------------------------------------
// -------------------------------------------------------------------------------------

// This function activates the undulated motion of the snake
void undulated_motion() {
  for(int i = 0; i < 360; i++) {
  
    float brads = i * 3.1415 / 180.0; 

    for(int j=0; j<N_SERVOS; j++){  
      
      if(motion_snake == UNDULATED) {
        while(is_running == 0) {
          if(motion_snake != UNDULATED) {
            reset();
            return;
          } else {
            continue;
          }
        }
        if(dir_snake == FORWARD) {
          rotate(j, 90 + offset + amplitude * sin(frequency * brads + (wavelength * j * 2 * 3.1415) / (N_SERVOS - 1)));
        } else {
          rotate(j, 90 + offset + amplitude * sin(-frequency * brads + (wavelength * j * 2 * 3.1415) / (N_SERVOS - 1))); 
        }  
      } else {
        reset();
        return;
      }
    }
   delay(10);
  }
}

// Updates the speed of the inchworm
void update_speed_inchworm(double s) {
  speed_inchworm = s;
}

// Updates the mode (0 -> stop, 1 -> start)
void update_mode(int m) {
  is_running = m;
}

// Updates the amplitude
void update_amplitude(double amp) {
  if(amp >= 20 && amp <= 70) {
    amplitude = amp;
  }
}

// Updates the wavelength
void update_wavelength(double wl) {
  if(wl >= 0 && wl <= 3) {
    wavelength = wl;
  }
}

// Updates the frequency
void update_frequency(double f) {
  if(f >= 0.5 && f <= 12) {
    frequency = f;
  }
}

// Updates the offset
void update_offset(double off) {
  if(off >= -10 && off <= 10) {
    offset = off;
  }
}

void update_direction(direction d) {
  if(d == FORWARD || d == BACKWARD) {
    dir_snake = d;
  }
}

void update_motion(motion mo) {
  motion_snake = mo;

  if(mo == CONCERTINA || mo == INCHWORM) {
    dir_snake = FORWARD;
  }
}

// This function resets the snake
void reset() {
  dir_snake = NO_MOVE;
  frequency = DEFAULT_FREQ;
  wavelength = DEFAULT_WL;
  offset = DEFAULT_OFF;  
  amplitude = DEFAULT_AMP;
  speed_inchworm = DEFAULT_SPEED_INCH;
  straight();
}


// -------------------------------------------------------------------------------------
// SETUP FUNCTION
// -------------------------------------------------------------------------------------
void setup() {  

  Serial.begin(9600); 
  Serial.println("INIT SNAKE FLIPPER");

  Serial.print("WIFI ...");
  WiFi.begin(ssid, password);
  Serial.print("Connecting to Wifi...");
  Serial.print("\n");

  while (WiFi.status() != WL_CONNECTED) {
    Serial.print(".");
    delay(500);
  }

  Serial.println("");
  Serial.println("Wifi connected");
  Serial.println(WiFi.localIP());

  
  server.on("/reset", HTTP_POST, [](AsyncWebServerRequest *request) {
    if(request->hasParam("value", true)) {
      AsyncWebParameter* p = request->getParam("value", true);
      int value = p->value().toInt();

      if(value == 0) {
        motion_snake = NONE;
      }
      request->send(200, "text/html", "good"); 
    } else {
      request->send(404, "text/html", "Error reset"); 
    }
  });

  server.on("/mode", HTTP_POST, [](AsyncWebServerRequest *request){
    if(request->hasParam("value", true)) {
      AsyncWebParameter* p = request->getParam("value", true);
      int value = p->value().toInt();

      update_mode(value);
      request->send(200, "text/html", "good"); 

    } else {
      request->send(404, "text/html", "Error mode"); 
    }
  });

  server.on("/motion", HTTP_POST, [](AsyncWebServerRequest *request){
    if(request->hasParam("value", true)) {
      AsyncWebParameter* p = request->getParam("value", true);
      int value = p->value().toInt();

      if(value == 1) {
        update_motion(UNDULATED);
      } else if(value == 0) {
        update_motion(CONCERTINA);
      } else if(value == 2) {
        update_motion(INCHWORM);
      }
      request->send(200, "text/html", "good"); 
    } else {
      request->send(404, "text/html", "Error motion"); 
    }
  });

  server.on("/params", HTTP_POST, [](AsyncWebServerRequest *request){
    if(request->hasParam("amp", true)) {
      AsyncWebParameter* p = request->getParam("amp", true);
      double value = p->value().toInt();
      update_amplitude(value);

      request->send(200, "text/html", "good"); 

    } else if(request->hasParam("wl", true)) {
      AsyncWebParameter* p = request->getParam("wl", true);
      double value = p->value().toInt();
      update_wavelength(value);

      request->send(200, "text/html", "good"); 

    } else if(request->hasParam("freq", true)) {
      AsyncWebParameter* p = request->getParam("freq", true);
      double value = p->value().toInt();
      update_frequency(value);

      request->send(200, "text/html", "good"); 

    } else if(request->hasParam("speed", true)) {
      AsyncWebParameter* p = request->getParam("speed", true);
      double value = p->value().toInt();
      update_speed_inchworm(value);

      request->send(200, "text/html", "good"); 

    } else if(request->hasParam("offset", true)) {
      AsyncWebParameter* p = request->getParam("offset", true);
      double value = p->value().toInt();
      update_offset(value);

      request->send(200, "text/html", "good"); 

    } else if(request->hasParam("off", true)) {
      AsyncWebParameter* p = request->getParam("off", true);
      double value = p->value().toInt();

      int off = 0;
      if(value <= 180) {
        off = map(value, 0, 180, -11, 11);
        if(off != offset) {
          update_offset(off);
        }
        request->send(200, "text/html", String(off)); 
      } else {
        request->send(200, "text/html", "nothing"); 
      }
    } else {
      request->send(404, "text/html", "baaaaaaaaaad"); 
    }
  });

  server.on("/direction", HTTP_POST, [](AsyncWebServerRequest *request){
        
    if(request->hasParam("value", true)) {
      AsyncWebParameter* p = request->getParam("value", true);
      int value = p->value().toInt();

      if(value == 1) {
        update_direction(FORWARD);
      } else if(value == 0) {
        update_direction(BACKWARD);
      } 

      request->send(200, "text/html", "ok direction");
    } else {
      request->send(404, "text/html", "Error direction"); 
    }
  });

  server.begin();

  driver.begin();
  driver.wakeup();
  driver.setPWMFreq(FREQUENCY_SERVO); // which frequency of our servos

  // Initialize all servo at their midpoint
  straight();

  delay(2000);
}

// -------------------------------------------------------------------------------------
// LOOP FUNCTION
// -------------------------------------------------------------------------------------
void loop() {
  
  if (WiFi.status() != WL_CONNECTED) {
    Serial.println("Wifi disconnected");
    WiFi.disconnect();
    delay(1000);
    WiFi.begin(ssid, password);
    while (WiFi.status() != WL_CONNECTED) {
      delay(1000);
      Serial.print(".");
    }
    Serial.println("");
    Serial.println("Wifi reconnected");
    server.begin();
  }

  if(is_running == 1) {
    switch(motion_snake){

      case CONCERTINA:
        concertina_motion();
        if(even == 1) {
          even = 0;
        } else {
          even = 1;
        }
        break;

      case INCHWORM:
        inchworm_motion();
        break;

      case UNDULATED:
        undulated_motion();
        break;

      case NONE:
        is_running = 0;
        break;  

      default:
        break;    
    } 
  } 
 
}

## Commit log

2023-05-31 servo_hold image
2023-06-02 3d_print added
    [head_piece.stl, main_piece.stl, piece_battery.stl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]
2023-06-02 app and command
    [head_piece.stl, main_piece.stl, piece_battery.stl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]
